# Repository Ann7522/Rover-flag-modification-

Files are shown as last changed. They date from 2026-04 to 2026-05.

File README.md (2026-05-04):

# 🚩 Mobile Robot Flag System (Yandex Rover Modification)

<p align="center">
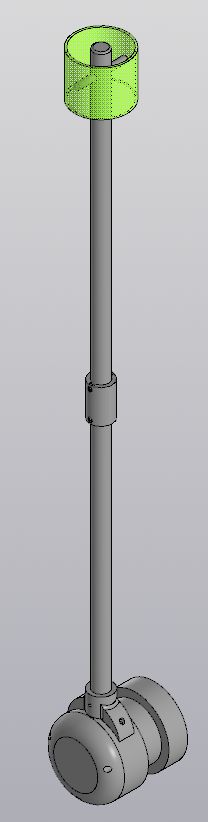
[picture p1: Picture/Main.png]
Флаг на ровере
  
</p>

## 📌 Overview
This project is a modular folding mount for the flag on the Yandex rover.   
The flag is designed to be visible from all sides thanks to its cylindrical retroreflective surface, which takes into account the physiological characteristics of information perception.   
The design includes a vibration damper (compensator) and a protection against unscrewing (a retaining ring).

**Status:** ✅ Concept proof — tested for vibrations, ⚠️ limited wind resistance

The system is optimized for:

* 3D printing (FDM)
* Easy transportation
* Vibration resistance

---

## 🧩 Assembly Structure

The system consists of 5 main components:

* **Hub** – main mounting unit connected to the robot корпус
* **Retaining Ring** – prevents self-unscrewing under vibration
* **Adapter1** – threaded connection to Hub
* **Compensator** – vibration damping element
* **Adapter2** – supports reflective flag panel

---

## ⚙️ Key Features

* Modular design
* Foldable construction for transport
* Cylindrical reflective flag for 360° visibility
* Anti-loosening mechanism (Retaining Ring)
* Vibration compensation system

<p align="center">
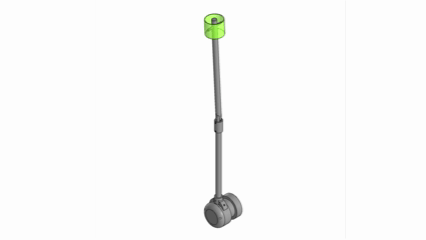
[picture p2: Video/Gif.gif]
Demonstration of the folding mechanism
  
  <br>
  <em>Animation of the folding mechanism</em>
</p>

---

## 🧪 Engineering Notes

### Material

All parts are manufactured using **PETG**:

* good impact resistance
* suitable for outdoor use
* better than PLA for dynamic loads

---

### ⚠️ Limitations

* PETG threads may degrade over time
* System resonance occurs at **~14–20 Hz**
* Compensator effectiveness depends on real damping properties
* Wind speed up to **7 m/s** ✅
* Wind speed (survival) up to 9 m/s (risk of fracture) ⚠️
  
---

## 📊 Performance Analysis

| Parameter | Result |
| --- | --- |
| Natural Frequency | ~18–22 Hz |
| Wind Load | ~1.5 N |
| Bending Moment | ~0.6–0.9 Nm |
| Safety Factor | >10 |

📟 Сalulations [Complete calculations of wind and vibration loads](https://github.com/Ann7522/Rover-flag-modification-/blob/main/dogs/calculations.md)

---

## 🎲 Recommendations

* Use threaded inserts for durability
* Add rubber/TPU layer in compensator
* Apply thread locker if needed
* Avoid operation in resonance conditions

---

## 🔧 Assembly

1. Attach the **bush** to the rover using 3 M6 bolts (use large washers)
2. Screw the **adapter 1** into the bush (M20×2.5 thread)
3. Attach the **retaining ring** to adapter 1 and secure it with 3 M3 screws (2 into the bush, 1 into adapter 1)
4. Install the **compensator** between adapters 1 and 2
5. Put **adapter 2** in **adapter 1** and fix it with M3 bolts
6. Fix **compnsator** with 2 M3 screws
7. Wrap it with reflective tape
   
---

## 🚀 Future Improvements

* TPU-based damping system
* Metal pin inserts 
* Improved aerodynamics

---

## 👨‍💻 Author

Chebotarev Andrey

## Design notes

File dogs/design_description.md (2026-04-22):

# Design Description

## Concept

The flag must reflect light from all angles and be visible to both pedestrians and drivers. A cylindrical retroreflective flag was designed. The modular design allows easy transport and integration of other solutions.

## Components

### Bushing
- Cylindrical, 3 blocks
- Block 1: 3×M6 mounting holes + M20×2.5 thread
- Block 2: Access for nuts inside rover
- Block 3: 90 mm depth for internal fixation

### Adaptor 1
- Screws into Bushing (M20×2.5 thread)
- Connects to Adaptor 2 with 2×M3 screws
- Rounded section allows folding

### Adaptor 2
- Holds the circular reflective panel
- Connects to Adaptor 1 via two rectangular interfaces

### Retaining Ring
- Prevents self-unscrewing
- 2×M3 screws into Bushing + 1×M3 screw into Adaptor 1

### Compensator
- Vibration damping element
- Located between Adaptor 1 and Adaptor 2
- Material: TPU (recommended) or PETG

## Flag Dimensions

Based on human height (≈175 cm) and seated driver eye level (≈110 cm). Optimal viewing angle: 15–30° downward. Final height: **770 mm**.

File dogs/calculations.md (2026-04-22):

# Engineering Calculations

## Material Properties (PETG)

| Property | Value |
|---|---|
| Young's modulus (E) | 2000 MPa |
| Yield strength (σ_y) | 50 MPa |
| Density | 1.27 g/cm³ |
| Damping ratio with Compensator | 0.15 |

---

## 1. Vibration Analysis (H = 770 mm)

### Natural Frequency
*I = π × d⁴ / 64 = 7.85×10⁻⁹ m⁴
*k = 3 × E × I / H³ = 103.2 N/m
*f₀ = (1/2π) × √(k/m) = 5.71 Hz

### With Compensator

| Frequency (Hz) | Input (g) | T | Output (g) | Stress (MPa) |
|---|---|----|---|---|
| 5.7 (resonance) | 0.7 | 2.2 | 1.54 | 11.9 |
| 10 | 1.5 | 1.10 | 1.65 | 12.7 |
| 15 | 2.0 | 0.80 | 1.60 | 12.4 |
| 20 | 2.0 | 0.60 | 1.20 | 9.3 |

**Margin:** 50 / 11.9 = **4.2×** ✅

---

## 2. Wind Load Analysis (H = 770 mm, d = 20 mm)

| Wind (m/s) | F (N) | σ (MPa) | Deflection (mm) | Status |
|---|---|---|---|---|
| 5 | 0.28 | 13.8 | 6.8 | ✅ Safe |
| 6 | 0.41 | 20.1 | 9.8 | ✅ Safe |
| 7 | 0.55 | 27.0 | 13.2 | ✅ Safe |
| 8 | 0.72 | 35.3 | 17.5 | ⚠️ Caution |
| 9 | 0.92 | 45.1 | 22.4 | ⚠️ Risk |
| 10 | 1.13 | 55.4 | 27.4 | ❌ Failure |

---

## 3. Summary Table

| Load case | Max stress (MPa) | Margin | Status |
|---|---|---|---|
| Vibration (with Compensator) | 11.9 | 4.2× | ✅ |
| Wind 7 m/s | 27.0 | 1.85× | ✅ |
| Wind 8 m/s | 35.3 | 1.42× | ⚠️ |
| Wind 9 m/s | 45.1 | 1.11× | ⚠️ |
| Wind 10 m/s | 55.4 | 0.90× | ❌ |

**Final verdict:**
- ✅ Vibration-safe with Compensator
- ⚠️ Wind-safe only up to 7 m/s
- ❌ Do not use in wind >9 m/s

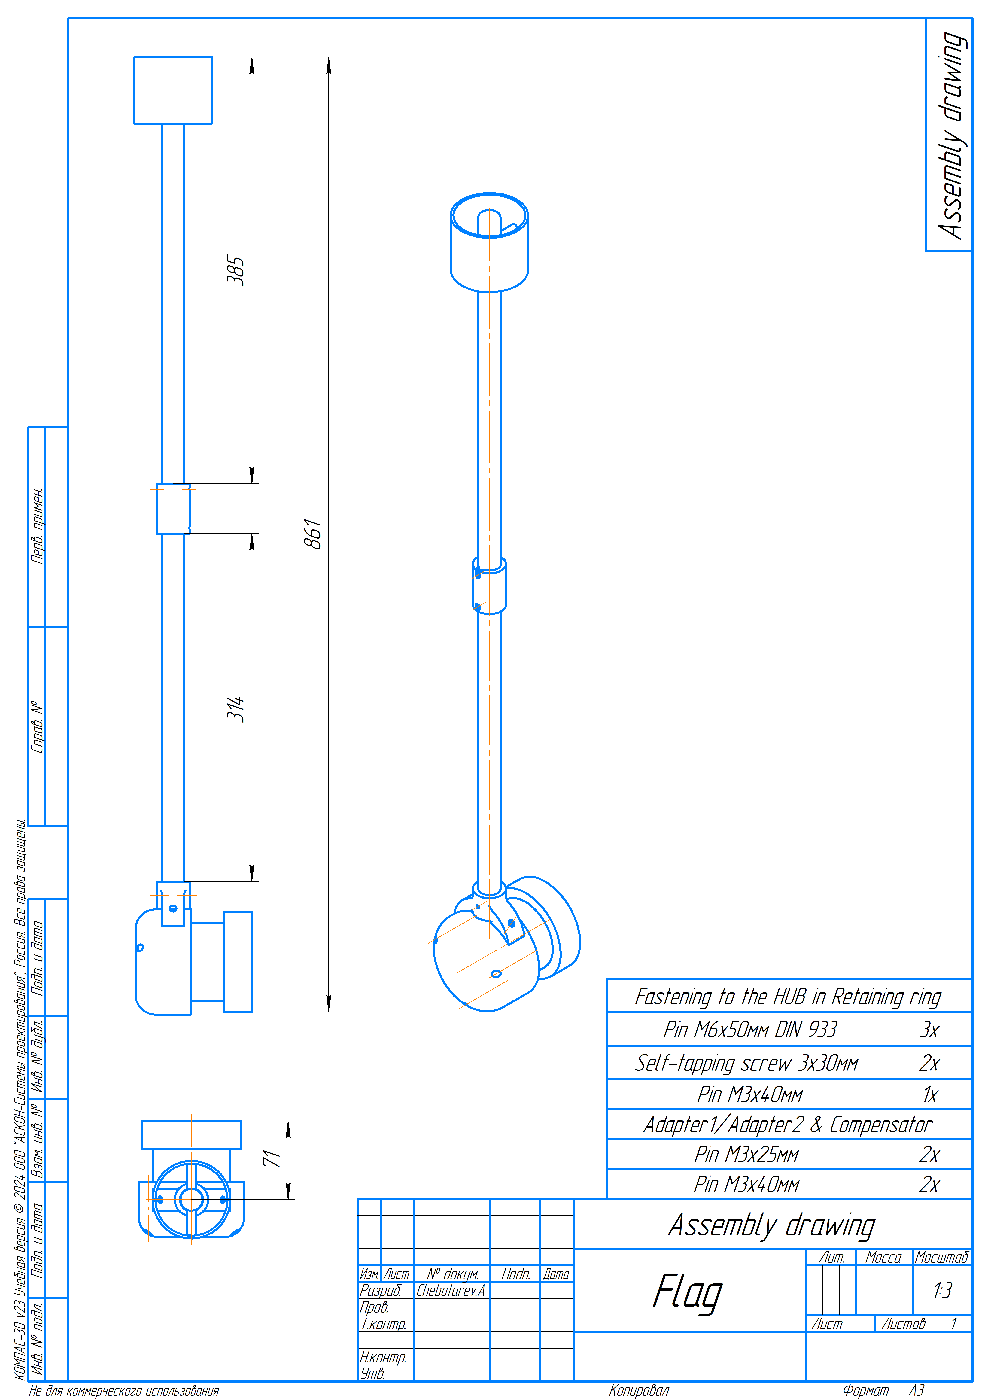
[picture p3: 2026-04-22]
dogs/Drawlings/Flag.png

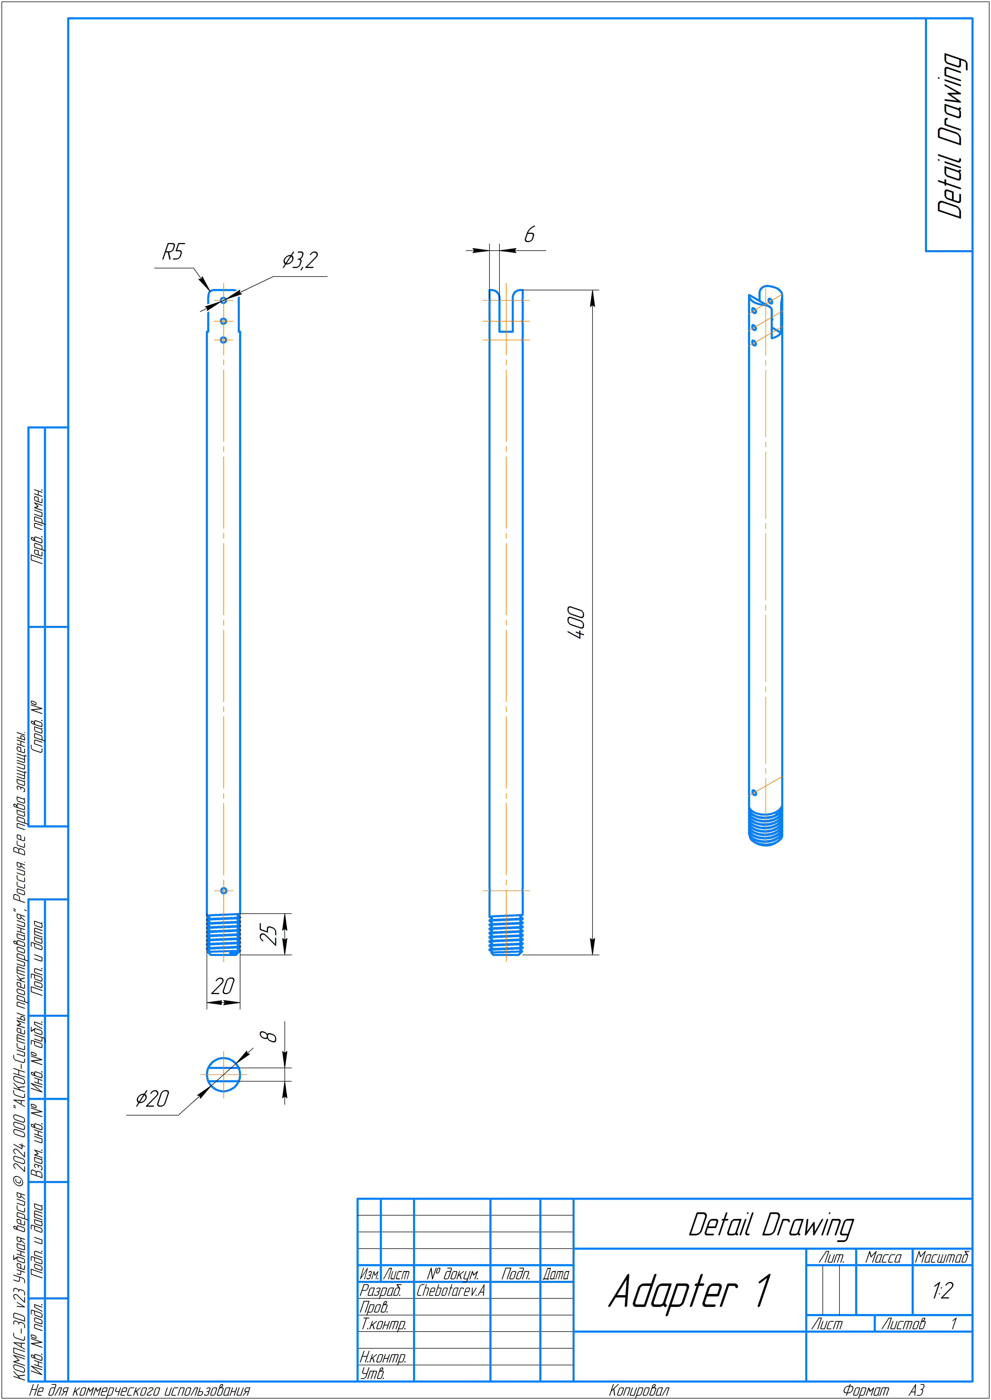
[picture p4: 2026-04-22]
dogs/Drawlings/Adapter1.png

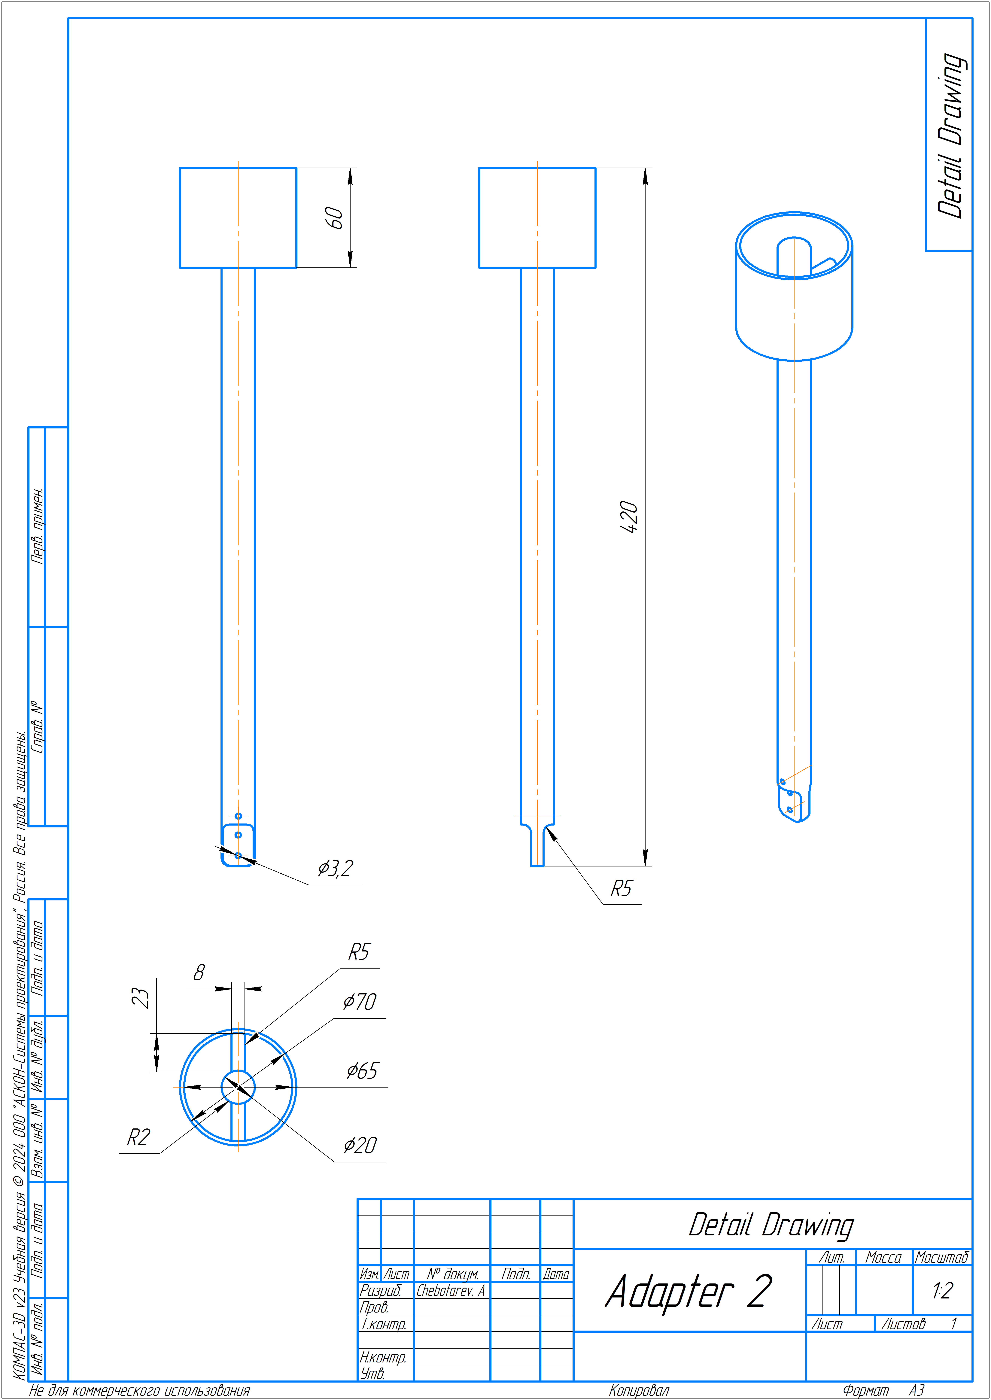
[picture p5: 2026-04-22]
dogs/Drawlings/Adapter2.png

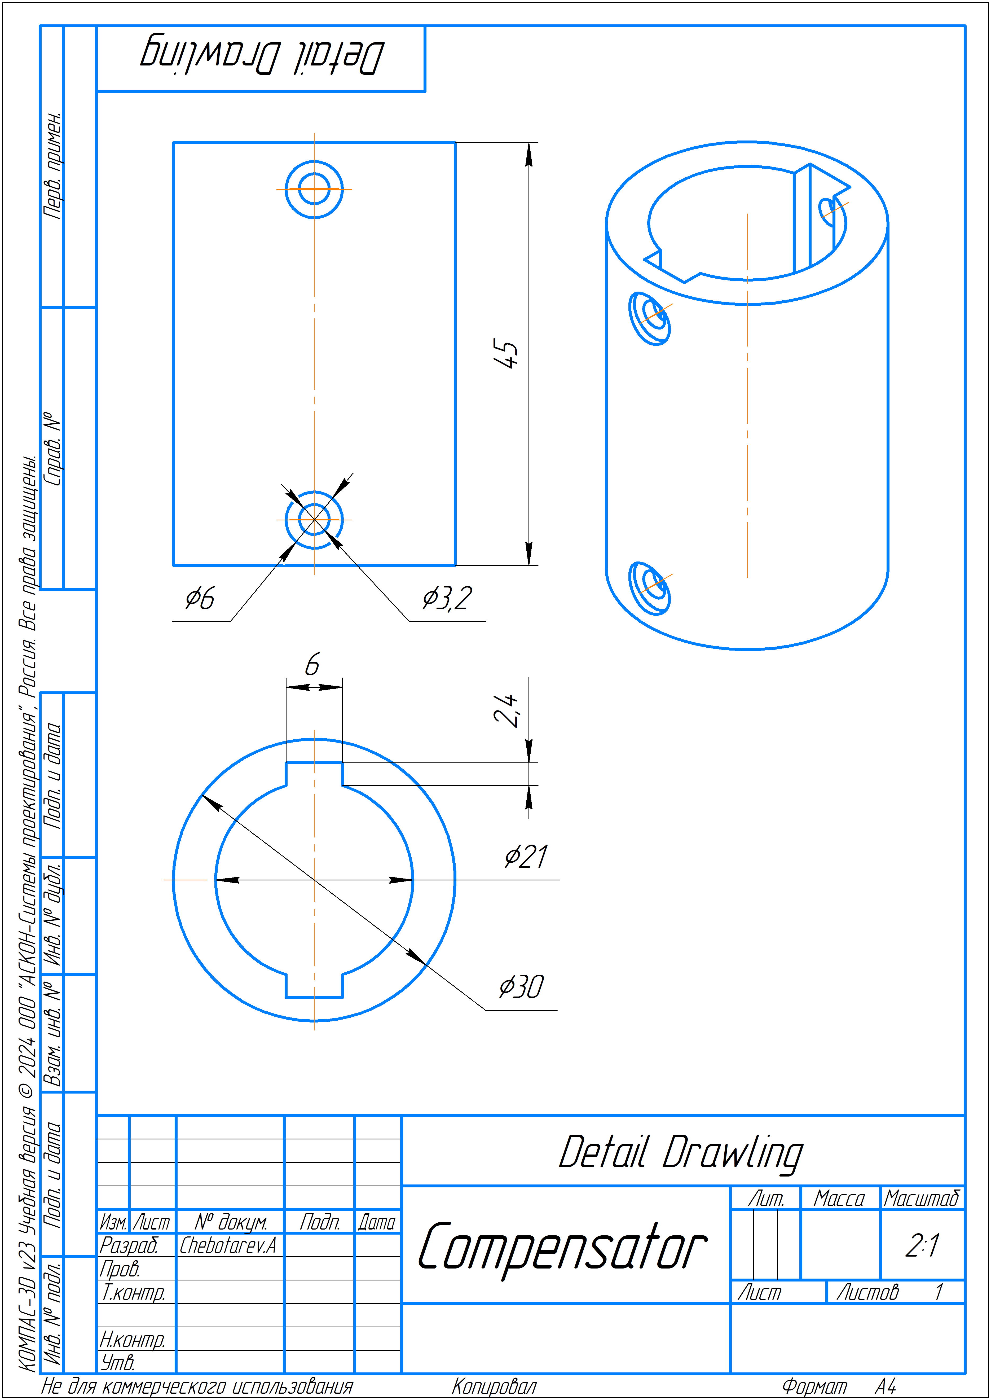
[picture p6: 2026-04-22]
dogs/Drawlings/Compensator.png

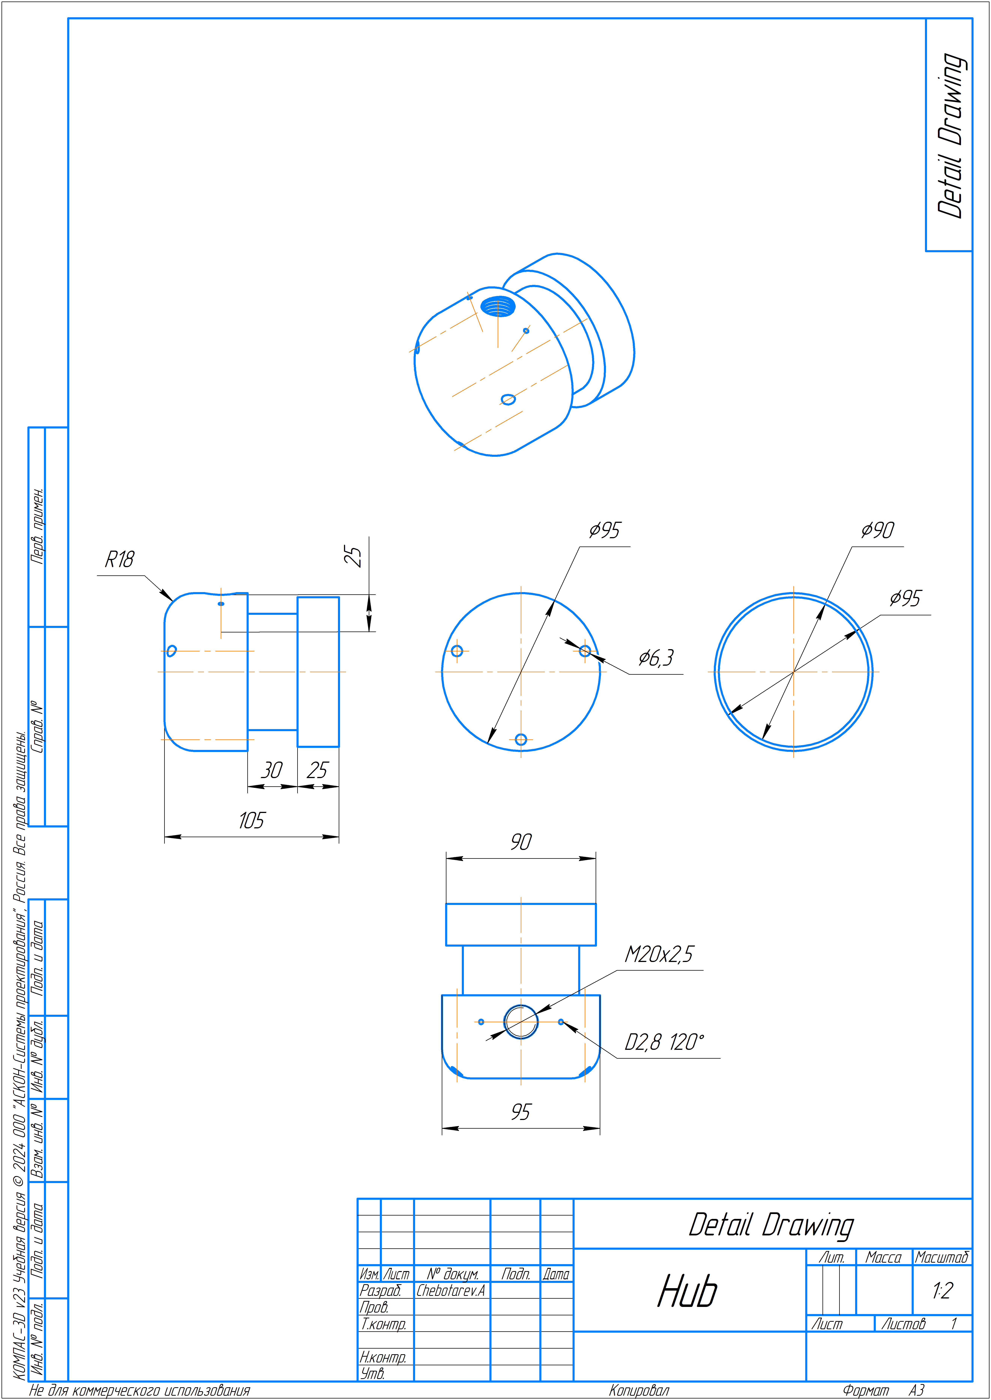
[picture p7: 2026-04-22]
dogs/Drawlings/Hub.png

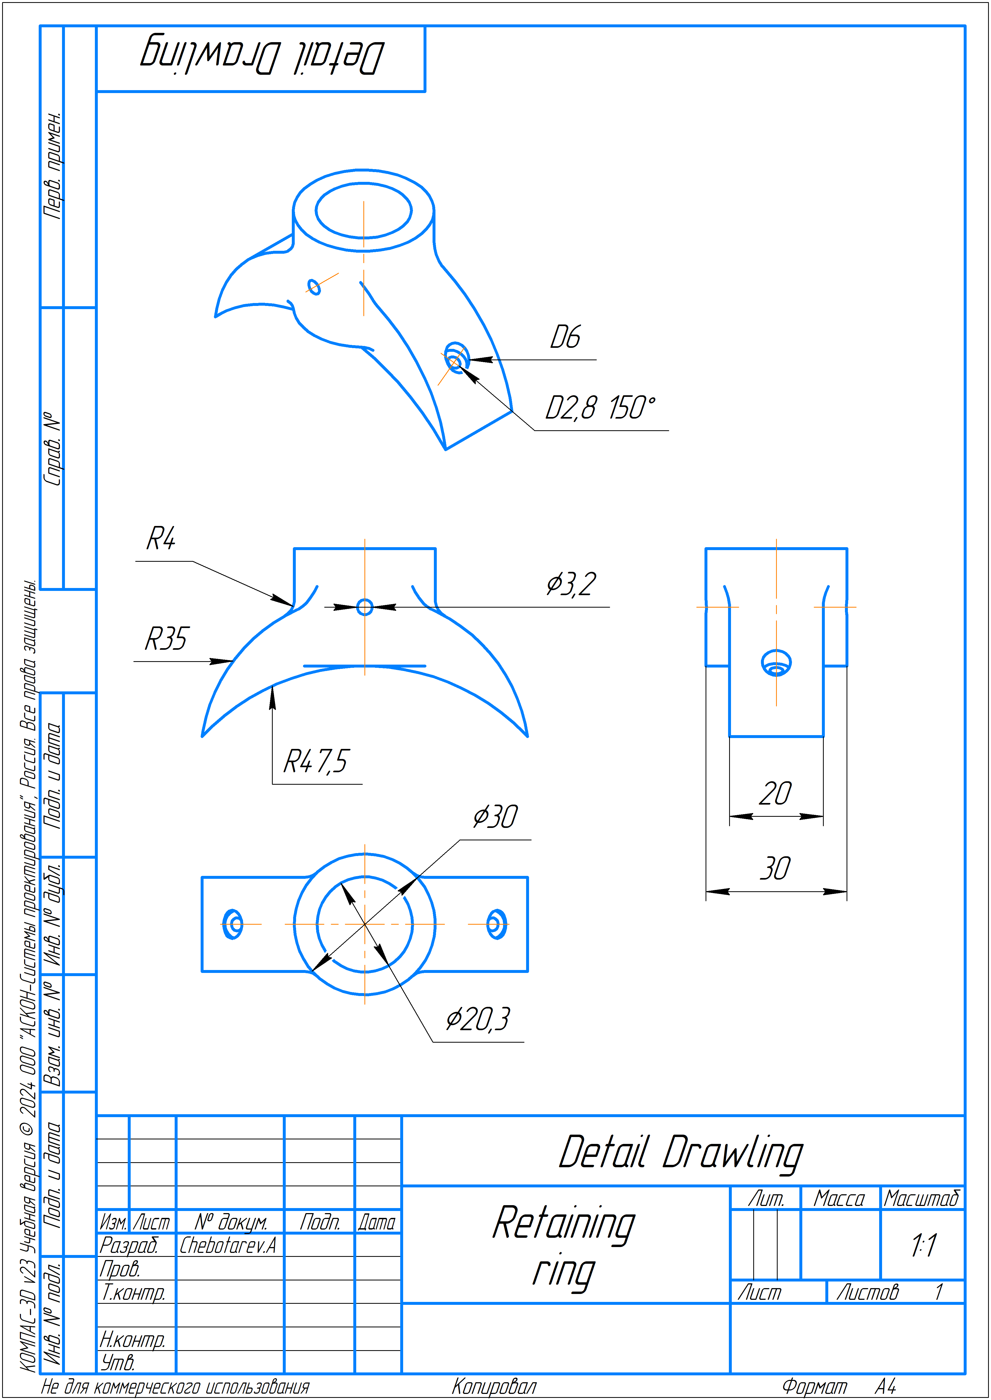
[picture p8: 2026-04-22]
dogs/Drawlings/Retaining ring.png

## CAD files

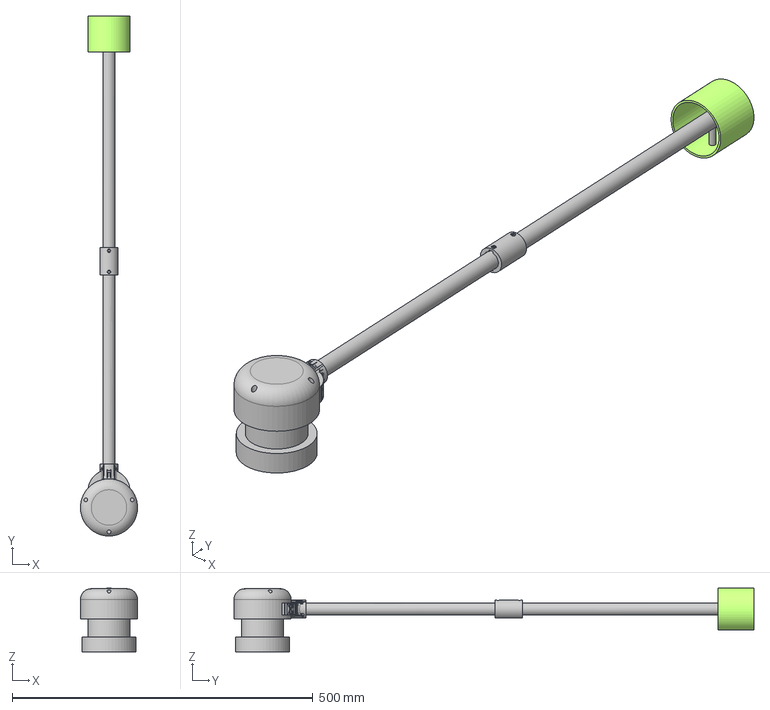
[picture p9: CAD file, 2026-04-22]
Models/Step/Flag.step
95.0 x 863.8 x 106.0 mm

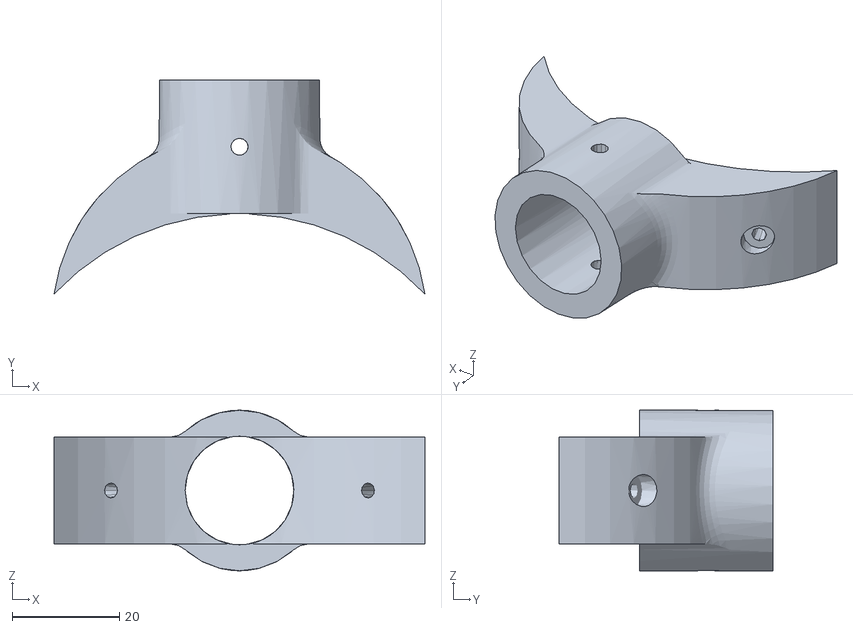
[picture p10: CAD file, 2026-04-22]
Models/Stl/Reteaning ring.stl
69.3 x 40.0 x 30.0

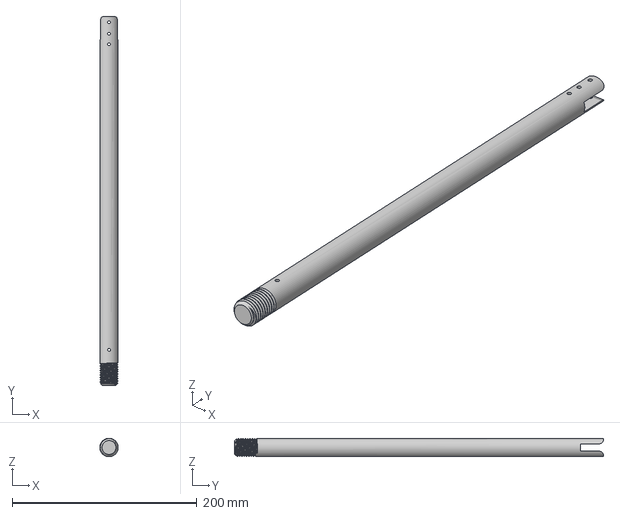
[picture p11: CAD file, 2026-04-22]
Models/Step/Adapter1.step
20.0 x 400.0 x 20.0 mm

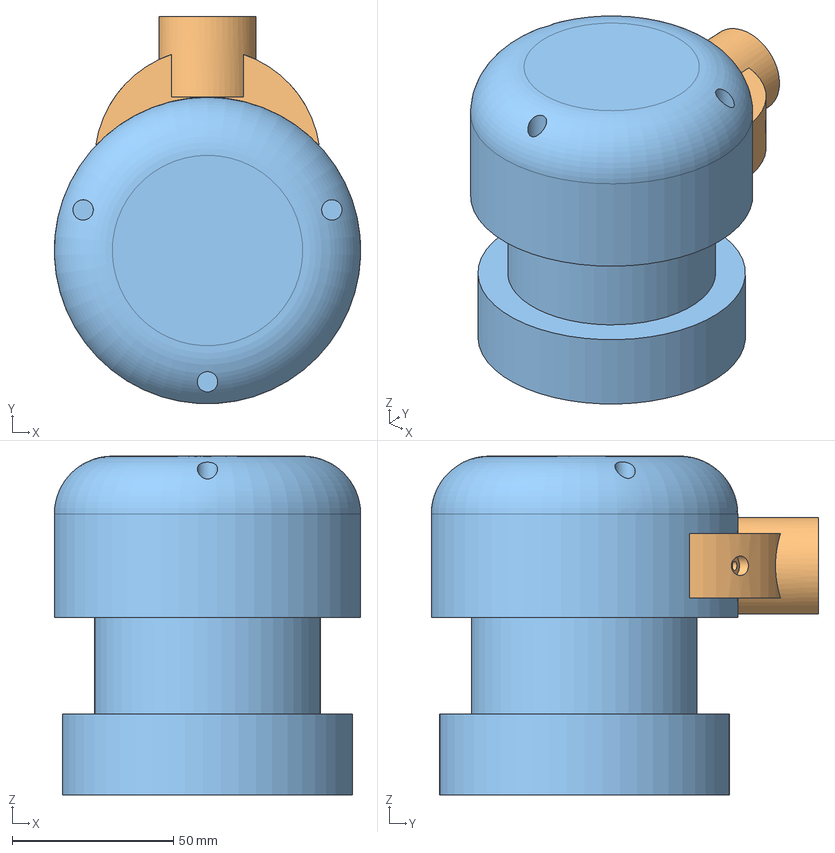
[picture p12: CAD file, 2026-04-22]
Models/Step/Hub.step
95.0 x 119.9 x 105.0 mm

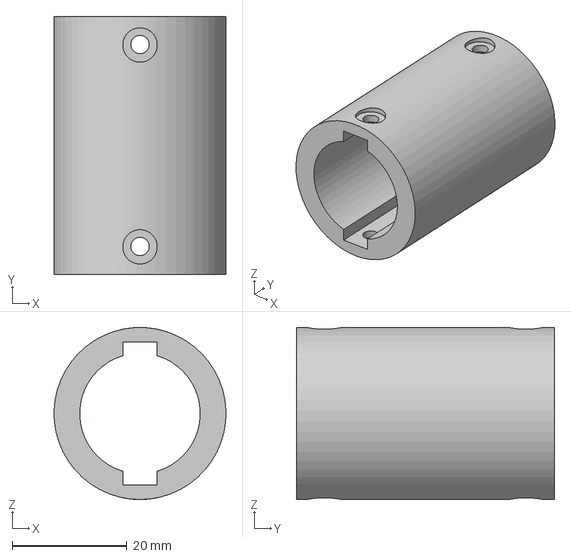
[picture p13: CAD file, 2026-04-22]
Models/Step/Compensator.step
30.0 x 45.0 x 30.0 mm

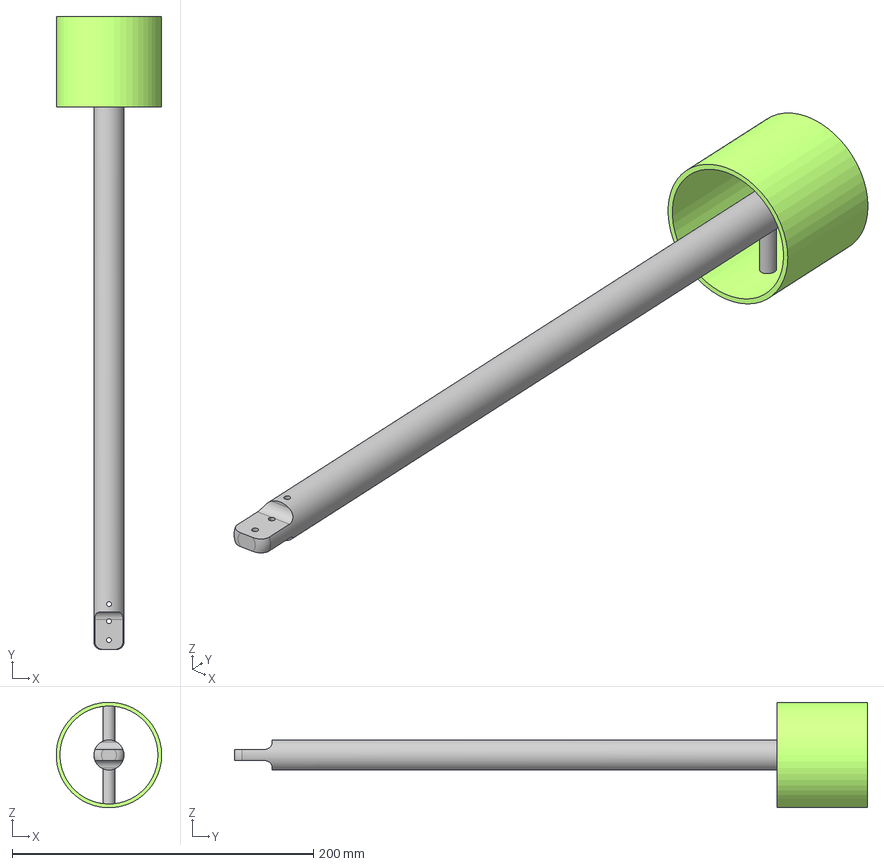
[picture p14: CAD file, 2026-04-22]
Models/Step/Adapter2.step
69.9 x 420.0 x 70.0 mm

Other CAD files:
Models/Step/Retaning ring.step
Models/Stl/Adapter1.stl
Models/Stl/Adapter2.stl
Models/Stl/Compensator.stl
Models/Stl/Flag.stl
Models/Stl/Hub.stl

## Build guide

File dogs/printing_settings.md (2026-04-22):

# FDM Printing Settings (PETG)

## Recommended Settings

| Parameter | Value |
|---|---|
| Nozzle temperature | 230–245°C |
| Bed temperature | 70–80°C |
| Layer height | 0.16–0.20 mm |
| Infill | **100%** |
| Wall lines | 4+ |
| Print speed | 40–50 mm/s |

## Print Orientation

| Part | Orientation |
|---|---|
| Bushing | Vertical (threads up) |
| Adaptor 1 | Vertical |
| Adaptor 2 | Horizontal |
| Retaining Ring | Flat on bed |
| Compensator | Flat on bed |

## Compensator (TPU)

| Parameter | Value |
|---|---|
| Nozzle temp | 220–235°C |
| Bed temp | 50–60°C |
| Speed | 20–30 mm/s |

## Post-Processing

1. Remove supports
2. Tap M3 threads
3. Chase M20×2.5 thread with a tap
